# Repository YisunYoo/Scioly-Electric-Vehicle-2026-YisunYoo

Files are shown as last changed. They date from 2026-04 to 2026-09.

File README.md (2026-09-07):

https://github.com/user-attachments/assets/1983c1e8-5cba-4048-b536-1d948fe2c736

# Scioly-Electric-Vehicle-2026
Full documentation for vehicle built for Science Olympiad division C Electric Vehicle event 
#
Built by Yisun "Ben" Yoo , Savannah Country Day School class of 2027
#
**#1 EV in 2026 Georgia state Science Olympiad competition**

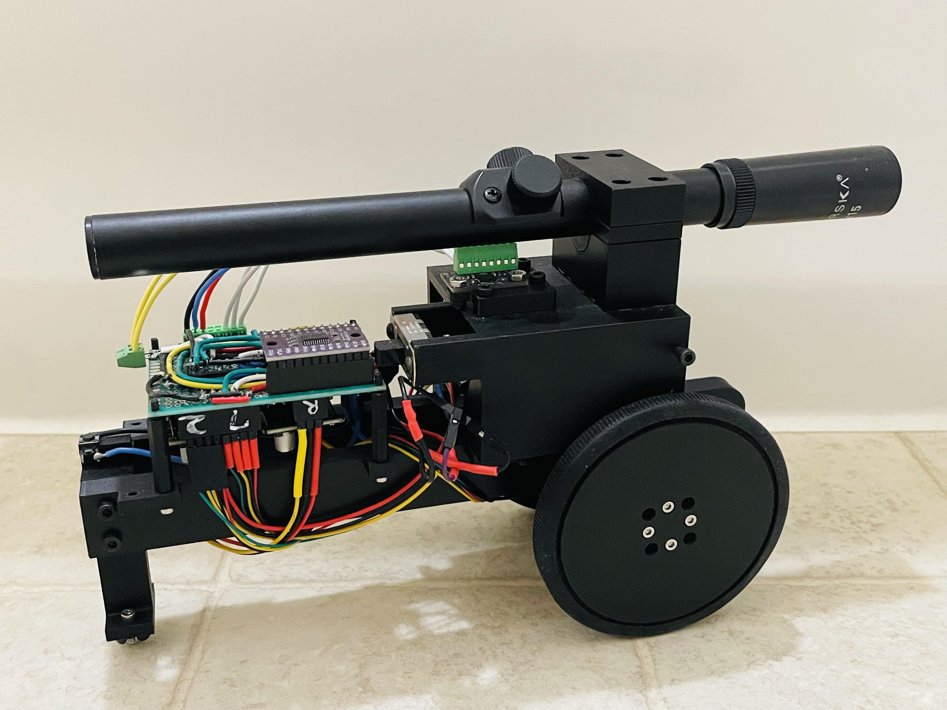
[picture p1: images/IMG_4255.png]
image failed


## Overview
Brief description of your vehicle's purpose and performance goals.

## Features
- Microcontroller: Arduino Nano ESP32
- IMU: BNO_08X
- Batteries: 8 AA 1.2v NiMH rechargeble
- Motor: 4015 gimbal BLDC motor (~400rpm max with 8 1.2vAA batteries)
- Encoder: AS5600 (0.087deg accuracy)

## Vehicle accuracy:
-   +- 1.5cm
-   +- 0.5s
-   gate width minimum: 13cm

## Quick Start
1. Install Arduino IDE
2. Install ESP32 board package
3. Upload `firmware/vehicle-controller.ino`

## Documentation
- [Circuit Design](circuit/diagrams/main-circuit.md)
- [Bill of Materials](docs/BOM.md)
- [3D Models](3d-models/)

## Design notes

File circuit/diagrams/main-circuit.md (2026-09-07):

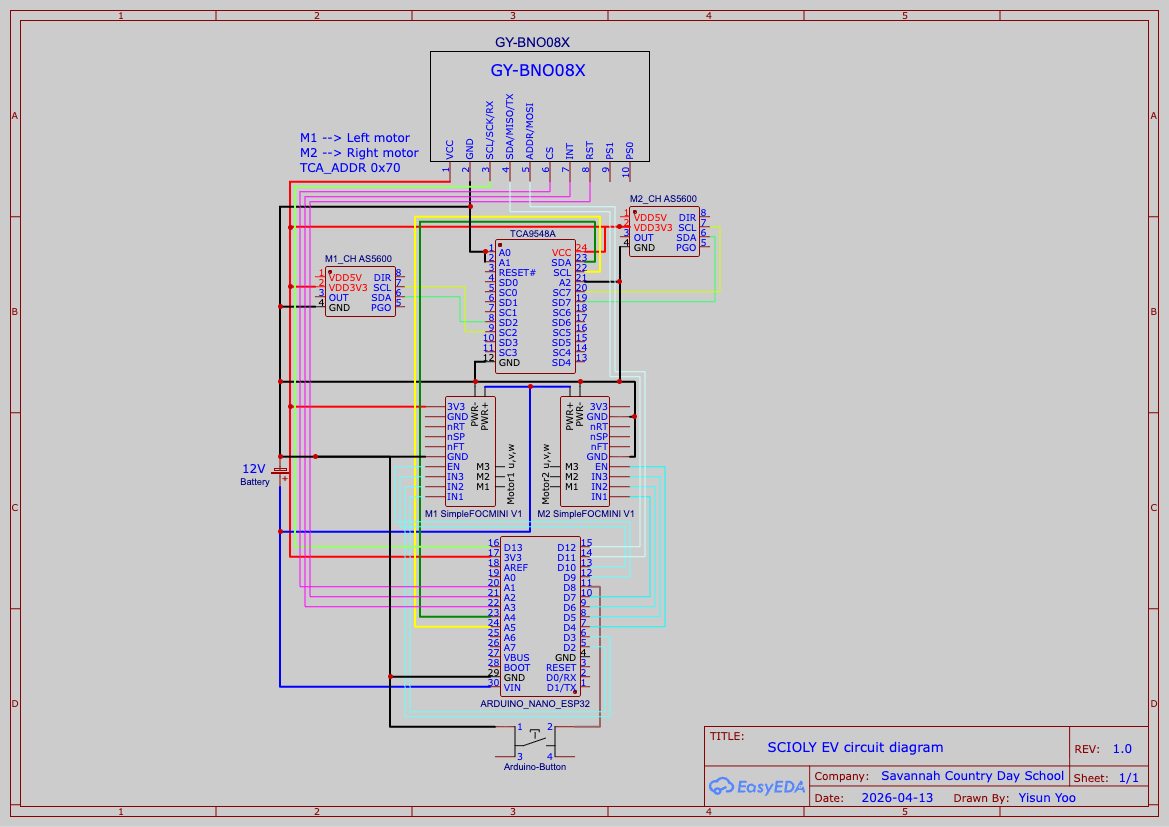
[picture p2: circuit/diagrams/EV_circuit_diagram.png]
image failed


# Circuit Specification

* PROJECT: SCIOLY EV Circuit Diagram
* DOCUMENTATION: Main Circuit Netlist and Pin Specifications
* REVISION: 1.0
* DATE: 2026-04-13
* COMPANY/TEAM: Savannah Country Day School
* DRAWN BY: Yisun Yoo
* CREATED BY: Yisun Yoo
* SOFTWARE: EasyEDA

# 1. SYSTEM SPECIFICATIONS & HARDWARE NOTES

* Microcontroller: Arduino Nano ESP32
* Power Source: 12V Battery (powers the Arduino VIN and motor drivers)
* Motor Driver Configuration: 
  - M1 = Left Motor Driver (SimpleFOCMini V1)
  - M2 = Right Motor Driver (SimpleFOCMini V1)
* I2C Multiplexer: TCA9548A (Address: 0x70)
  - All address pins (A0, A1, A2) are tied to GND.
* Motor: 4015 gimbal motor

# 2. POWER DISTRIBUTION & BUS RAILS

* 12V Main Rail:
  - Battery (+) ---> Arduino Nano ESP32 (Pin 30: VIN)
  - Battery (+) ---> M1 SimpleFOCMini V1 (PWR+)
  - Battery (+) ---> M2 SimpleFOCMini V1 (PWR+)

* 5V Logic Rail (VBUS):
  - Arduino Nano ESP32 (Pin 28: VBUS) ---> TCA9548A (Pin 24: VCC)
  - Arduino Nano ESP32 (Pin 28: VBUS) ---> M1_CH AS5600 Encoder (Pin 1: VDD5V)
  - Arduino Nano ESP32 (Pin 28: VBUS) ---> M2_CH AS5600 Encoder (Pin 1: VDD5V)

* 3.3V Logic Rail:
  - Arduino Nano ESP32 (Pin 17: 3V3) ---> GY-BNO08X IMU (Pin 1: VCC)
  - Arduino Nano ESP32 (Pin 17: 3V3) ---> M1 SimpleFOCMini V1 (3V3)
  - Arduino Nano ESP32 (Pin 17: 3V3) ---> M2 SimpleFOCMini V1 (3V3)

* Common Ground (GND):
  - Linked across Battery (-),
  - Arduino Nano ESP32 (Pin 29: GND),
  - TCA9548A (Pin 12: GND),
  - TCA9548A (Pins 1, 2, 3: A0/A1/A2),
  - GY-BNO08X (Pin 2: GND),
  - M1_CH AS5600 (Pin 5: GND),
  - M2_CH AS5600 (Pin 5: GND),
  - M1 SimpleFOCMini (GND),
  - M2 SimpleFOCMini (GND),
  - Arduino-Button (Pin 4).

# 3. PIN CONNECTIONS BY COMPONENT

[A] ARDUINO NANO ESP32
-------------------------------------------------------------------
* Pin 1  (D1/TX)   ---> TCA9548A (Pin 22: SCL)
* Pin 2  (D0/RX)   ---> TCA9548A (Pin 23: SDA)
* Pin 5  (D2)      ---> Arduino-Button (Pin 3)
* Pin 6  (D3)      ---> Tied to BOTH M1 (nRT) and M2 (nRT)
* Pin 7  (D4)      ---> M2 SimpleFOCMini V1 (nSP)
* Pin 8  (D5)      ---> M2 SimpleFOCMini V1 (nFT)
* Pin 9  (D6)      ---> M2 SimpleFOCMini V1 (EN)
* Pin 10 (D7)      ---> M2 SimpleFOCMini V1 (M3)
* Pin 11 (D8)      ---> M2 SimpleFOCMini V1 (M2)
* Pin 12 (D9)      ---> M2 SimpleFOCMini V1 (M1)
* Pin 13 (D10)     ---> M2 SimpleFOCMini V1 (IN3)
* Pin 14 (D11)     ---> M2 SimpleFOCMini V1 (IN2)
* Pin 15 (D12)     ---> M2 SimpleFOCMini V1 (IN1)
* Pin 16 (D13)     ---> M1 SimpleFOCMini V1 (IN1)
* Pin 17 (3V3)     ---> 3.3V Power Rail
* Pin 19 (A0)      ---> M1 SimpleFOCMini V1 (IN2)
* Pin 20 (A1)      ---> M1 SimpleFOCMini V1 (IN3)
* Pin 21 (A2)      ---> M1 SimpleFOCMini V1 (M1)
* Pin 22 (A3)      ---> M1 SimpleFOCMini V1 (M2)
* Pin 23 (A4)      ---> M1 SimpleFOCMini V1 (M3)
* Pin 24 (A5)      ---> M1 SimpleFOCMini V1 (EN)
* Pin 25 (A6)      ---> M1 SimpleFOCMini V1 (nFT)
* Pin 26 (A7)      ---> M1 SimpleFOCMini V1 (nSP)
* Pin 28 (VBUS)    ---> 5V Power Rail
* Pin 29 (GND)     ---> Common Ground Rail
* Pin 30 (VIN)     ---> 12V Battery (+)

[B] TCA9548A I2C MULTIPLEXER (Addr: 0x70)
-------------------------------------------------------------------
* Pin 1  (A0)      ---> GND
* Pin 2  (A1)      ---> GND
* Pin 3  (A2)      ---> GND
* Pin 5  (SD0)     ---> GY-BNO08X IMU (Pin 4: SDA/MISO/TX)
* Pin 6  (SC0)     ---> GY-BNO08X IMU (Pin 3: SCL/SCK/RX)
* Pin 7  (SD1)     ---> M1_CH AS5600 Left Encoder (Pin 4: SDA)
* Pin 8  (SC1)     ---> M1_CH AS5600 Left Encoder (Pin 3: SCL)
* Pin 9  (SD2)     ---> M2_CH AS5600 Right Encoder (Pin 4: SDA)
* Pin 10 (SC2)     ---> M2_CH AS5600 Right Encoder (Pin 3: SCL)
* Pin 12 (GND)     ---> GND
* Pin 22 (SCL)     ---> Arduino Nano ESP32 (Pin 1: D1/TX)
* Pin 23 (SDA)     ---> Arduino Nano ESP32 (Pin 2: D0/RX)
* Pin 24 (VCC)     ---> 5V Rail (VBUS)

[C] GY-BNO08X IMU SENSOR (Channel 0)
-------------------------------------------------------------------
* Pin 1 (VCC)        ---> 3.3V Rail
* Pin 2 (GND)        ---> GND
* Pin 3 (SCL/SCK/RX) ---> TCA9548A (Pin 6: SC0)
* Pin 4 (SDA/MISO/TX)---> TCA9548A (Pin 5: SD0)
* **Pins 5-10 (ADDR, CS, INT, RST, PS1, PS0) are UNCONNECTED.**

[D] M1_CH AS5600 ENCODER - LEFT MOTOR (Channel 1)
-------------------------------------------------------------------
* Pin 1 (VDD5V)  ---> 5V Rail (VBUS)
* Pin 3 (SCL)    ---> TCA9548A (Pin 8: SC1)
* Pin 4 (SDA)    ---> TCA9548A (Pin 7: SD1)
* Pin 5 (GND)    ---> GND
* **Pins 2 (VDD3V3), 6 (PGO), 7 (DIR) are UNCONNECTED.**

[E] M2_CH AS5600 ENCODER - RIGHT MOTOR (Channel 2)
-------------------------------------------------------------------
* Pin 1 (VDD5V)  ---> 5V Rail (VBUS)
* Pin 3 (SCL)    ---> TCA9548A (Pin 10: SC2)
* Pin 4 (SDA)    ---> TCA9548A (Pin 9: SD2)
* Pin 5 (GND)    ---> GND
* **Pins 2 (VDD3V3), 6 (PGO), 7 (DIR) are UNCONNECTED.**

[F] M1 SIMPLEFOCMINI V1 - LEFT MOTOR DRIVER
-------------------------------------------------------------------
* PWR+          ---> 12V Battery (+)
* PWR- / GND    ---> GND
* 3V3           ---> 3.3V Rail
* nRT           ---> Arduino Nano ESP32 (Pin 6: D3)
* nSP           ---> Arduino Nano ESP32 (Pin 26: A7)
* nFT           ---> Arduino Nano ESP32 (Pin 25: A6)
* EN            ---> Arduino Nano ESP32 (Pin 24: A5)
* M3            ---> Arduino Nano ESP32 (Pin 23: A4)
* M2            ---> Arduino Nano ESP32 (Pin 22: A3)
* M1            ---> Arduino Nano ESP32 (Pin 21: A2)
* IN3           ---> Arduino Nano ESP32 (Pin 20: A1)
* IN2           ---> Arduino Nano ESP32 (Pin 19: A0)
* IN1           ---> Arduino Nano ESP32 (Pin 16: D13)
* Motor1 u,v,w  ---> 3-Phase outputs to Left Motor

[G] M2 SIMPLEFOCMINI V1 - RIGHT MOTOR DRIVER
-------------------------------------------------------------------
* PWR+          ---> 12V Battery (+)
* PWR- / GND    ---> GND
* 3V3           ---> 3.3V Rail
* nRT           ---> Arduino Nano ESP32 (Pin 6: D3)
* nSP           ---> Arduino Nano ESP32 (Pin 7: D4)
* nFT           ---> Arduino Nano ESP32 (Pin 8: D5)
* EN            ---> Arduino Nano ESP32 (Pin 9: D6)
* M3            ---> Arduino Nano ESP32 (Pin 10: D7)
* M2            ---> Arduino Nano ESP32 (Pin 11: D8)
* M1            ---> Arduino Nano ESP32 (Pin 12: D9)
* IN3           ---> Arduino Nano ESP32 (Pin 13: D10)
* IN2           ---> Arduino Nano ESP32 (Pin 14: D11)
* IN1           ---> Arduino Nano ESP32 (Pin 15: D12)
* Motor2 u,v,w  ---> 3-Phase outputs to Right Motor

[H] ARDUINO-BUTTON (System Input)
-------------------------------------------------------------------
* Pin 3 ---> Arduino Nano ESP32 (Pin 5: D2)
* Pin 4 ---> GND

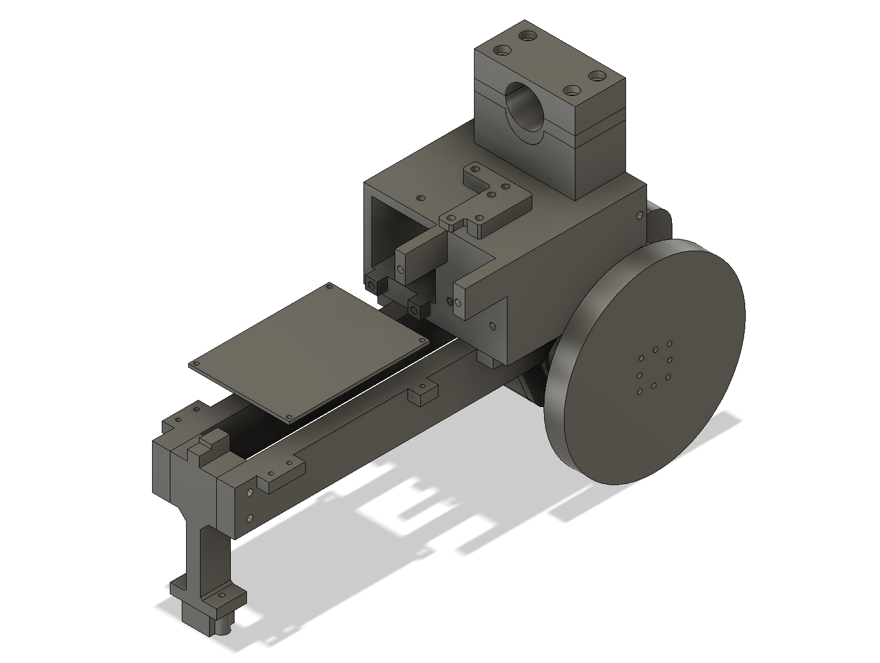
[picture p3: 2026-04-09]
images/3D model full view main.png

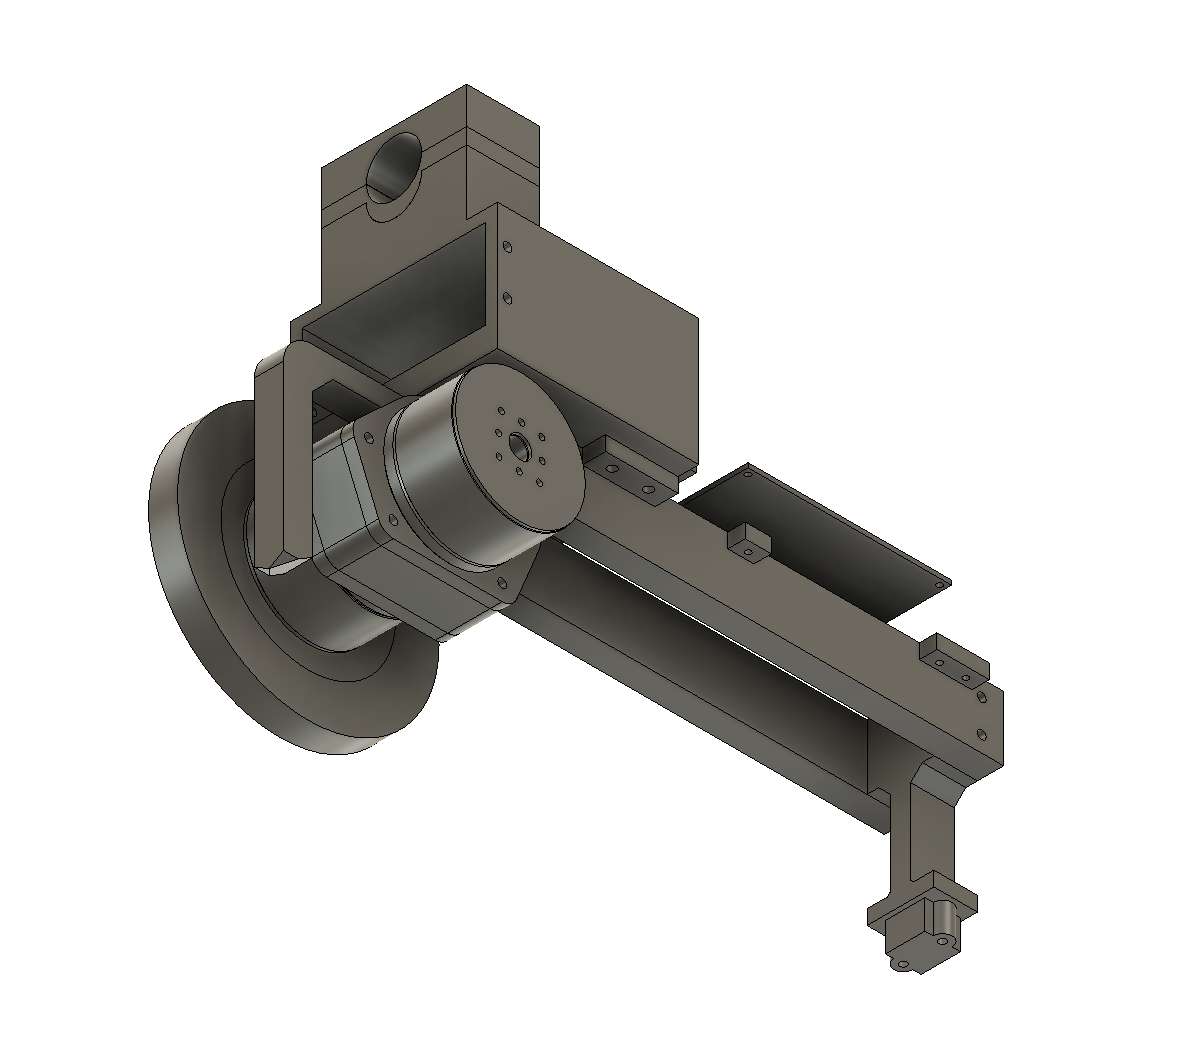
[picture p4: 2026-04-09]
images/3D model full view back.png

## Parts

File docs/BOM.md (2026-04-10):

## link to BOM

[link to BOM](https://docs.google.com/spreadsheets/d/1UVivWzAKgq3oz-N-Q3s3JLDuceGFrLYAt_yYQ4SD5Zs/edit?usp=sharing)

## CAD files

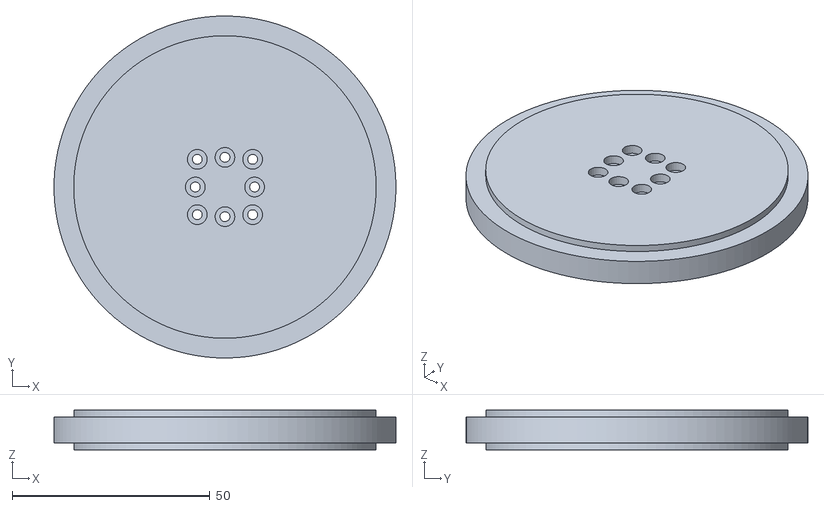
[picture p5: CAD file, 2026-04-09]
3d-models/wheel hub.stl
86.5 x 86.5 x 10.0

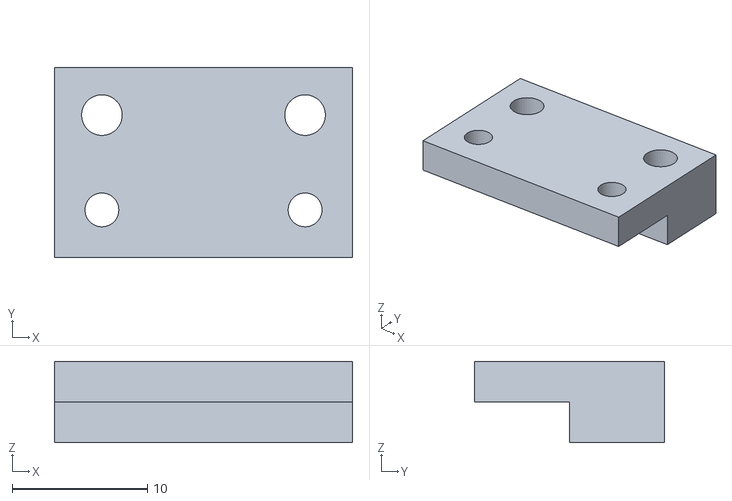
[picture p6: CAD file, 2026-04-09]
3d-models/IMU mount front.stl
22.0 x 14.0 x 6.00

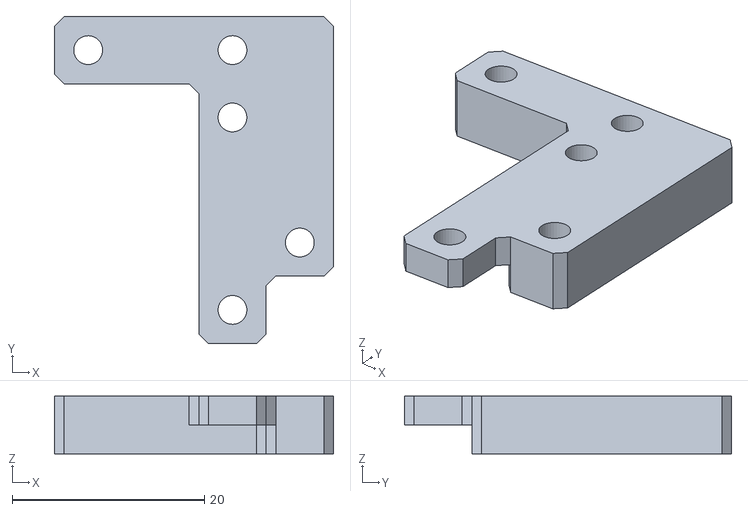
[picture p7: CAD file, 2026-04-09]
3d-models/IMU mount rear.stl
29.0 x 34.0 x 6.00

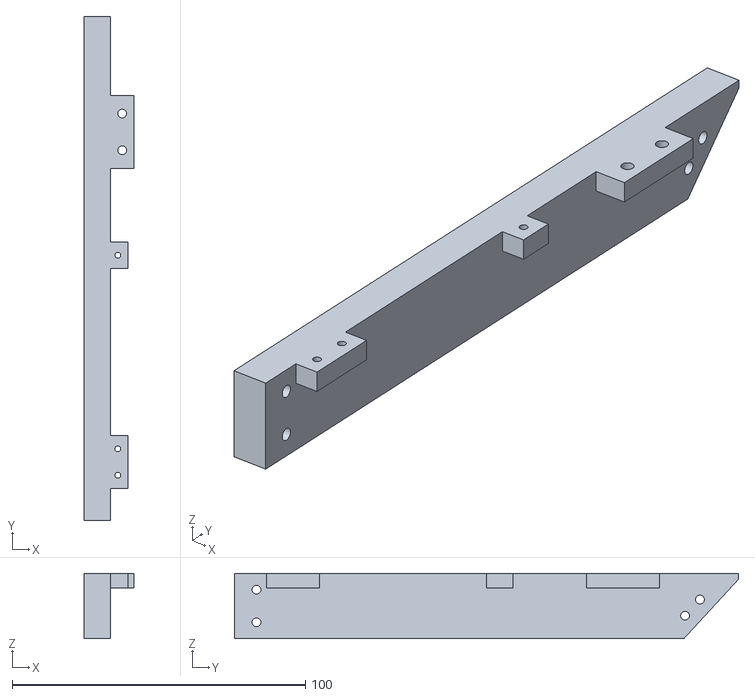
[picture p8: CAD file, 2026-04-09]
3d-models/right frame.stl
17.0 x 171.9 x 22.2

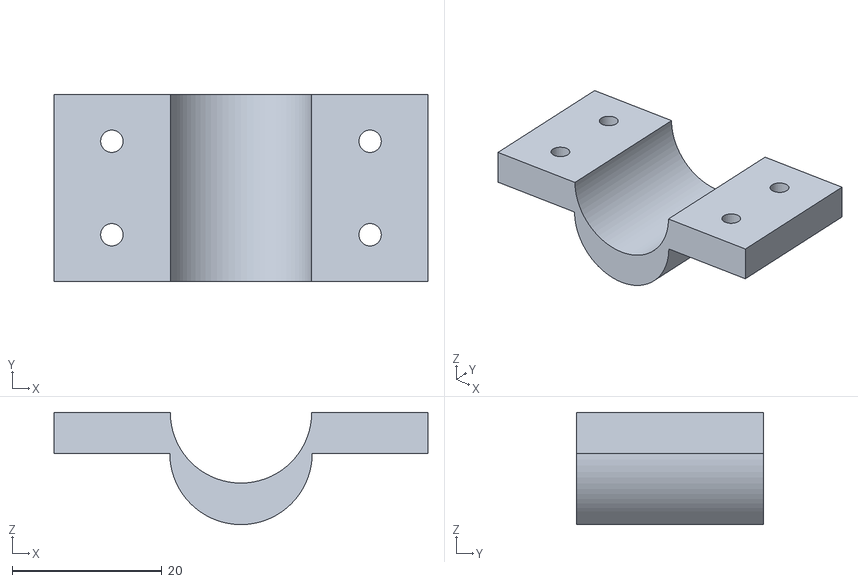
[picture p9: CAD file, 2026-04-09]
3d-models/heightadder.stl
50.0 x 25.0 x 15.0

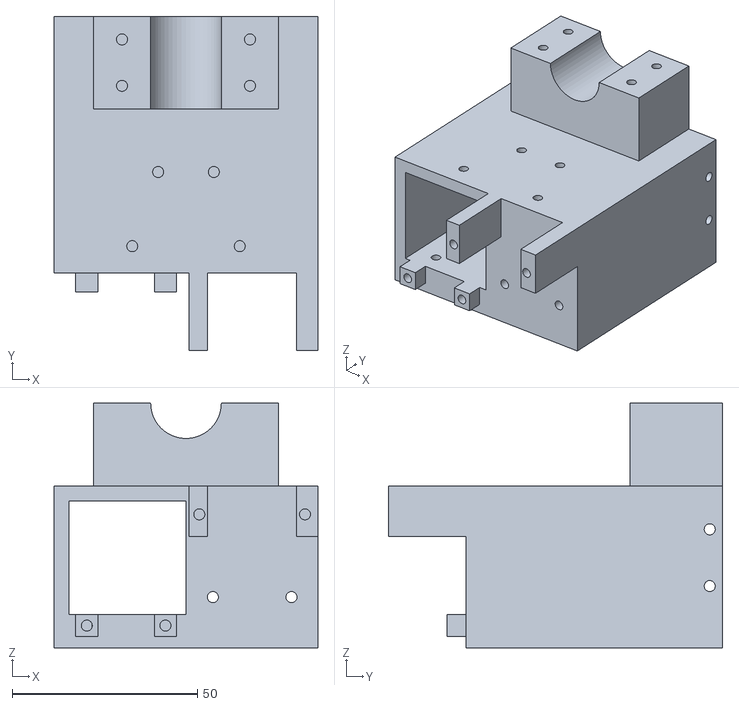
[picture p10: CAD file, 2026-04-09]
3d-models/battery holder.stl
71.2 x 90.2 x 66.0

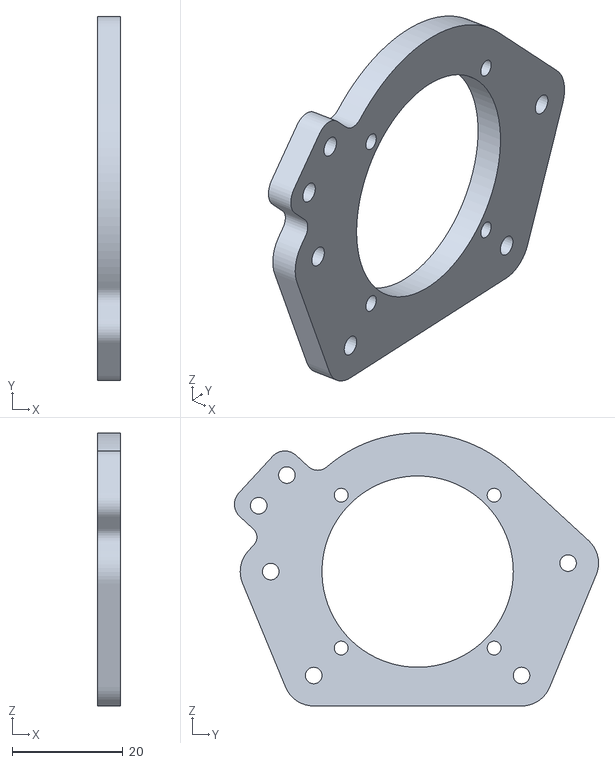
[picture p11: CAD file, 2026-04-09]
3d-models/Motor mount.stl
4.20 x 65.7 x 49.2

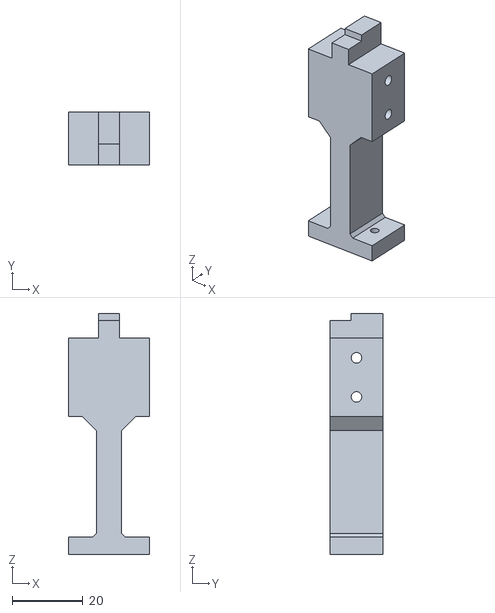
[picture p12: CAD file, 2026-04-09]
3d-models/rear stand.stl
23.0 x 15.0 x 68.3

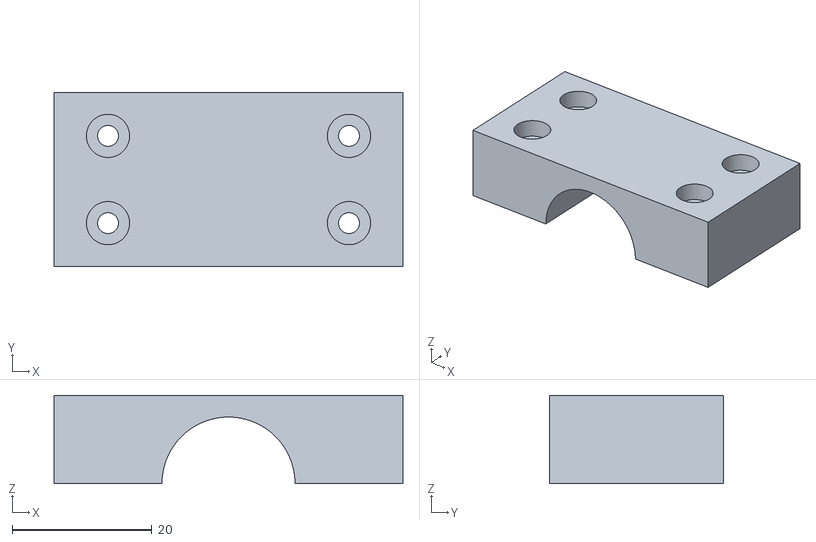
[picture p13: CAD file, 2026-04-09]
3d-models/scope top.stl
50.0 x 25.0 x 12.6

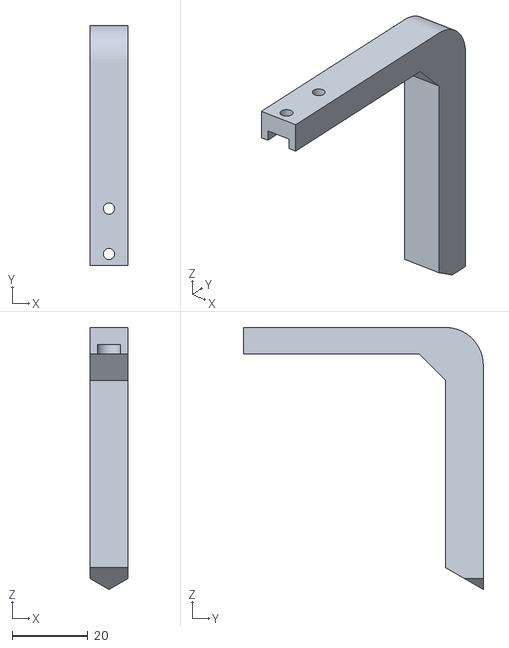
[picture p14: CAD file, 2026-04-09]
3d-models/MP.stl
10.0 x 63.4 x 69.3

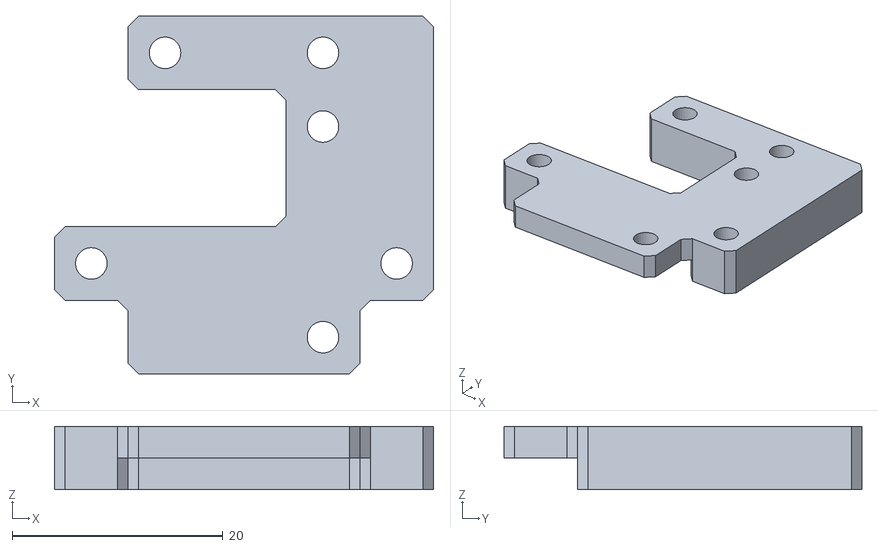
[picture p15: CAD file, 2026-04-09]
3d-models/IMU mount new.stl
36.0 x 34.0 x 6.00

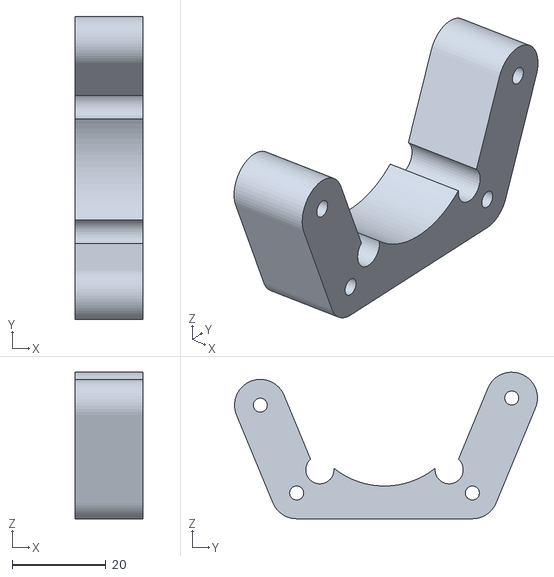
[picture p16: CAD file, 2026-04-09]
3d-models/spacer.stl
14.6 x 64.6 x 31.3

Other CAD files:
3d-models/left frame.stl

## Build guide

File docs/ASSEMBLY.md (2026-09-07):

Screenshot 2026-09-07 at 2 42 48 PM
Screenshot 2026-09-07 at 2 43 19 PM

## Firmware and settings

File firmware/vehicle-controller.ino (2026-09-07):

//by Yisun Yoo
//This is the final version. DO NOT CHANGE EXCEPT parameters of RUNSTART inside loop()

/*
  this code uses modified PID and odometry to move the differential drive robot with two motors from one point to another point as precise as possible, with a gate to pass through.
  the given sensors are
  1. two AS5600 encoder
  - Operating Voltage: 3.3V
  - Resolution: 12-bit
  - Accuracy: 0.087°
  - Output Method: I2C
  - Interface: GH1.25-4Pin

  2.BNO 055  absolute orientation sensor also with I2C

  The vehicle has wheel radius of 3.0cm, wheel diameter of 9.0cm (with wheel base of 8.1cm)
  The motor is 4015 gimbal motor 
  - wire to wire resistance of 4.8 ohms
  - rated voltage up to 24v and current max up to 4A
  - 11 pole pairs 

  The vehicle runs on eight AA batteries, with 1.2v rated voltage (rechargeble NiMH aa 2800mah)
  the voltage output when fully charged was meausred around 10V (+- 0.5V)
  The code should assume the batteries are always fully charged

  The vehicle has a reference point called measuring point(MP) 
  MP of the vehicle is placed 5cm in front of the vehicle midpoint of the axle connecting the two driving wheels.
  MP is the point that is measured from the target. (goal: MP = target)

  center line is the line connecting the starting point and the end point

  task: 
  1. the vehicle MP is placed on top of the starting point, and the vehicle is set to face the target point
  2. once the button is pressed, the vehicle should start to run
  3. the vehicle should pass though the gate
  4. the gate is placed to the left of the center line, and is placed on the midway between starting point and endpoint
  5. the outer side of the gate is fixed 100cm away from the center line
  6. the distance between the outer side and the inner side of the gate is chosen by us, and should be one of the inpput variable (gate distance < 100cm , the code should aim for going though middle of the gates)
  7. the vehicle should arrive at target point, which is defined by the distance, and target distance is another input variable. the possible distance vary from 700cm to 1000cm
  8. lastly, the vehicle should arrive at the target point at exact time set, which is the last input variable. the possible target time vary from 10 seconds to 20 seconds.
  9. the score is calculated as 100 + Distance Score + Time Score + Bonuses + Run Penalties
    c. Distance Score = 2.0 pt/cm x Vehicle Distance.
    d. Time Score = Absolute value of (Target Time - Run Time)
    e. Can Bonus = -0.5 x (110 - Inside Can Distance)
  10. the less score is better.

  plan:
  1. the vehicle will take three actions: moveStrait(from (y1 to y2 or x1 to x2))); turn(ang) degrees; and final precision movement for vehicle MP to precisely placed on target
*/

#include <Wire.h>
#include <SimpleFOC.h>
#include <AS5600.h>
#include "SparkFun_BNO08x_Arduino_Library.h"

AS5600 as5600;
BNO08x myIMU;

// ---- Motor pins ----
#define M1_U D2
#define M1_V D3
#define M1_W D10
#define M1_EN D9

#define M2_U D7
#define M2_V D6
#define M2_W D5
#define M2_EN D4

// ---- Encoder channels ----
#define M1_CH 2
#define M2_CH 7

// ---- Button ----
#define Button D8
const unsigned long debounce_ms = 50;
bool last_button = HIGH;
unsigned long last_change = 0;

// ---- IMU ----
#define BNO08X_CS A1
#define BNO08X_INT A3
#define BNO08X_RST A2
#define BNO08X_REPORT_INTERVAL_MS 25

struct EulerAngles {
  float yawDeg;
};

// ---- TCA9548A ----
#define TCA_ADDR 0x70
static void tcaSelect(uint8_t channel) {
  Wire.beginTransmission(TCA_ADDR);
  Wire.write(1 << channel);
  Wire.endTransmission();
}

bool readMuxedAS5600(uint8_t channel, uint16_t &raw, float &angleDeg, const char *label) {
  tcaSelect(channel);
  raw = as5600.rawAngle();
  const int err = as5600.lastError();
  if (err != AS5600_OK) {
    Serial.print("AS5600 read failed on ");
    Serial.print(label);
    Serial.print(" channel ");
    Serial.print(channel);
    Serial.print(" error ");
    Serial.println(err);
    return false;
  }

  angleDeg = raw * (360.0f / 4096.0f);
  return true;
}

float imuRawYawDeg = 0.0f;
float imuYawOffsetDeg = 0.0f;
bool imuHasOrientation = false;
bool imuReportsEnabled = false;
bool imuDebugPrinted = false;

// ---- Forward direction signs (adjust if needed) ----
const float M1_DIR = -1.0f;   // forward is + for motor1
const float M2_DIR = 1.0f;    // forward is + for motor2

MagneticSensorI2C sensor1 = MagneticSensorI2C(AS5600_I2C);
MagneticSensorI2C sensor2 = MagneticSensorI2C(AS5600_I2C);
BLDCMotor motor1 = BLDCMotor(11);
BLDCMotor motor2 = BLDCMotor(11);
BLDCDriver3PWM driver1 = BLDCDriver3PWM(M1_U, M1_V, M1_W, M1_EN);
BLDCDriver3PWM driver2 = BLDCDriver3PWM(M2_U, M2_V, M2_W, M2_EN);


// ========================== TUNE ================================= //
const float WHEEL_DIAMETER = 9.0f;
const float WHEEL_RADIUS = WHEEL_DIAMETER / 2.0f;
const float WHEEL_BASE = 8.5f;
const float MIN_VOLTAGE = 0.8f; //min voltage vehicle moves stably
const float max_voltage = 12.0f;

// ---- values ----
float M1_zero_pos = 0.0f;  //deg
float M2_zero_pos = 0.0f;  //deg
float M1_pos = 0.0f;       //rad
float M2_pos = 0.0f;       //rad
float x_pos = 0.0f;        //cm
float y_pos = 0.0f;        //cm
float yaw = 0.0f;          //deg
float startTime = 0.0f; //s
float runTime = 0.0f; //s

// ---- odometry ----
float M1_prev = 0.0f;      //rad
float M2_prev = 0.0f;      //rad
float yaw_prev = 0.0f;     //deg
float deg_prev = PI/2.0f;

uint16_t raw1 = 0, raw2 = 0;
float angle1 = 0, angle1_prev = 0, cumulative_angle1 = 0;
float angle2 = 0, angle2_prev = 0, cumulative_angle2 = 0;

// --- move equal ---
float M1_pos_ref = 0.0f;
float M2_pos_ref = 0.0f;

static inline float wrapPi(float a) {
  while (a > PI) a -= 2.0f * PI;
  while (a < -PI) a += 2.0f * PI;
  return a;
}

// ================================================ IMU FUNCTIONS ================================================

float clampUnit(float value) {
  if (value > 1.0f) {
    return 1.0f;
  }
  if (value < -1.0f) {
    return -1.0f;
  }
  return value;
}

float wrap180(float deg) {
  while (deg > 180.0f) {
    deg -= 360.0f;
  }
  while (deg < -180.0f) {
    deg += 360.0f;
  }
  return deg;
}

EulerAngles quaternionToEuler(float real, float i, float j, float k) {
  EulerAngles angles;
  const float sinyCosp = 2.0f * (real * k + i * j);
  const float cosyCosp = 1.0f - 2.0f * (j * j + k * k);
  angles.yawDeg = atan2f(sinyCosp, cosyCosp) * RAD_TO_DEG;

  return angles;
}

bool setIMUReports() {
  Serial.println("Setting desired reports");
  if (myIMU.enableGameRotationVector(BNO08X_REPORT_INTERVAL_MS) == true) {
    Serial.println(F("Rotation vector enabled"));
    Serial.println(F("Output in form i, j, k, real, accuracy"));
    imuReportsEnabled = true;
    imuDebugPrinted = false;
    delay(100);
    return true;
  }

  Serial.println("Could not enable rotation vector");
  imuReportsEnabled = false;
  delay(100);
  return false;
}

void zeroYaw() {
  if (!imuHasOrientation) {
    return;
  }

  imuYawOffsetDeg = imuRawYawDeg;
  yaw = 0.0f;
}

bool beginIMU() {
  Serial.println();
  Serial.println("BNO08x Read Example");

  const bool started = myIMU.beginSPI(BNO08X_CS, BNO08X_INT, BNO08X_RST);

  Serial.print("myIMU.begin: ");
  Serial.println(started ? "OK" : "FAIL");
  if (!started) return false;

  Serial.println("BNO08x found!");
  setIMUReports();

  const unsigned long retry_start_ms = millis();
  unsigned long last_retry_ms = retry_start_ms;
  while (!imuReportsEnabled && (millis() - retry_start_ms) < 1500) {
    if (myIMU.wasReset()) {
      Serial.print("sensor was reset ");
      setIMUReports();
    } else if ((millis() - last_retry_ms) >= 150) {
      last_retry_ms = millis();
      setIMUReports();
    }
    delay(10);
    Serial.println("?");
  }

  if (!imuReportsEnabled) return false;

  Serial.println("Reading events");
  delay(100);

  yaw = 0.0f;
  imuRawYawDeg = 0.0f;
  imuYawOffsetDeg = 0.0f;
  imuHasOrientation = false;

  Serial.println("beginIMU: done");
  return true;
}

float getYawDeg() {
  return yaw;
}
bool updateIMU_latest() {
  if (myIMU.wasReset()) {
    Serial.print("sensor was reset ");
    if (!setIMUReports()) return false;
  }

  if (!imuReportsEnabled) {
    if (!setIMUReports()) {
      return false;
    }
  }

  // Match the vendor examples: only poll once when INT says data is ready.
  // Repeatedly calling getSensorEvent() until false can force a 500ms timeout
  // inside the library and trigger an IMU reset when no fresh packet is queued.
  if (digitalRead(BNO08X_INT) != LOW) {
    return false;
  }

  if (!myIMU.getSensorEvent()) {
    return false;
  }

  if (myIMU.getSensorEventID() != SENSOR_REPORTID_GAME_ROTATION_VECTOR) {
    return false;
  }

  const float qi = myIMU.getGameQuatI();
  const float qj = myIMU.getGameQuatJ();
  const float qk = myIMU.getGameQuatK();
  const float qr = myIMU.getGameQuatReal();
  const EulerAngles a = quaternionToEuler(qr, qi, qj, qk);

  imuRawYawDeg = a.yawDeg;
  if (!imuHasOrientation) { imuHasOrientation = true; zeroYaw(); }

  yaw = wrap180(imuYawOffsetDeg - imuRawYawDeg); // update global yaw

  const bool got = true;
  if (got && !imuDebugPrinted) {
    //Serial.println("IMU stream active");
    imuDebugPrinted = true;
  }
  return got;
}

// ================================================ IMU FUNCTIONS END ================================================

void setupMotor(BLDCMotor &motor, BLDCDriver3PWM &driver, MagneticSensorI2C &sensor, uint8_t ch) {
  //encoder
  tcaSelect(ch);
  sensor.init(&Wire);
  motor.linkSensor(&sensor);
  sensor.min_elapsed_time = 0.001;

  //driver
  driver.voltage_power_supply = 10.6f;
  driver.voltage_limit = 10.0f;
  driver.pwm_frequency = 25000;
  driver.init();
  motor.linkDriver(&driver);
  float max_velocity = 30.0;                       // rad/s
  float motor_frequency_hz = max_velocity / (2 * PI); // ~16 Hz
  float filter_cutoff_hz = motor_frequency_hz * 5;    // ~80 Hz
  motor.LPF_velocity.Tf = 1.0 / (2.0 * PI * filter_cutoff_hz); 

  motor.controller = MotionControlType::velocity; //voltage
  motor.PID_velocity.P = 0.2;
  motor.PID_velocity.I = 20;

  motor.voltage_sensor_align = 3.0f;
  motor.sensor_direction = Direction::UNKNOWN;

  motor.init();
  motor.initFOC();
}

void resetValues() {
  // Encoder 1 snapshot (degrees)
  if (!readMuxedAS5600(M1_CH, raw1, angle1, "M1")) return;
  angle1_prev = angle1;
  cumulative_angle1 = angle1;
  M1_zero_pos = cumulative_angle1;   // NOTE: stored in degrees

  // Encoder 2 snapshot (degrees)
  if (!readMuxedAS5600(M2_CH, raw2, angle2, "M2")) return;
  angle2_prev = angle2;
  cumulative_angle2 = angle2;
  M2_zero_pos = cumulative_angle2;   // NOTE: stored in degrees

  zeroYaw();

  // Reset odometry state
  x_pos = 0.0f;
  y_pos = 0.0f;

  M1_pos = 0.0f;
  M2_pos = 0.0f;
  M1_prev = 0.0f;
  M2_prev = 0.0f;

  // Heading convention:
  // radians: PI/2 = North (+Y)
  // degrees: 0 = North
  deg_prev = PI * 0.5f;
  yaw = 0.0f;
  yaw_prev = 0.0f;

  M1_pos_ref = 0.0f;
  M2_pos_ref = 0.0f;

  startTime = millis() / 1000.0f;
}

void updateOdometry() {

  // ---- Encoder 1 (degrees -> cumulative degrees -> radians) ----
  if (!readMuxedAS5600(M1_CH, raw1, angle1, "M1")) return;

  float delta_angle1 = angle1 - angle1_prev;
  if (delta_angle1 < -180.0f) delta_angle1 += 360.0f;
  if (delta_angle1 >  180.0f) delta_angle1 -= 360.0f;

  cumulative_angle1 += delta_angle1;
  angle1_prev = angle1;

  // M1_zero_pos is in degrees
  M1_pos = (cumulative_angle1 - M1_zero_pos) * (PI / 180.0f) * M1_DIR; // radians


  // ---- Encoder 2 ----
  if (!readMuxedAS5600(M2_CH, raw2, angle2, "M2")) return;

  float delta_angle2 = angle2 - angle2_prev;
  if (delta_angle2 < -180.0f) delta_angle2 += 360.0f;
  if (delta_angle2 >  180.0f) delta_angle2 -= 360.0f;

  cumulative_angle2 += delta_angle2;
  angle2_prev = angle2;

  //yaw calculation
  updateIMU_latest();
  while (yaw < 0.0f) yaw += 360.0f;
  while (yaw >= 360.0f) yaw -= 360.0f;

  // M2_zero_pos is in degrees
  M2_pos = (cumulative_angle2 - M2_zero_pos) * (PI / 180.0f) * M2_DIR; // radians

  // ---- Differential drive odometry ----
  float D_l = radToCm(M1_pos - M1_prev);         // cm
  float D_r = radToCm(M2_pos - M2_prev);         // cm
  float D_avg = 0.5f * (D_l + D_r);              // cm
  float D_yaw_deg = yaw - yaw_prev;
  if (D_yaw_deg > 180.0f) D_yaw_deg -= 360.0f;
  if (D_yaw_deg < -180.0f) D_yaw_deg += 360.0f;
  float D_ang = -D_yaw_deg * PI / 180.0f;   // minus sign: yaw is CW+, math angle is CCW+


  float heading_mid = degToRad(yaw_prev) + 0.5f * D_ang;   // radians, PI/2 is North
  x_pos += D_avg * cosf(heading_mid);            // +X east
  y_pos += D_avg * sinf(heading_mid);            // +Y north

  deg_prev = wrapPi(deg_prev + D_ang);           // radians

  // Convert radians heading to compass-like yaw:
  // yaw = 0 at North, clockwise positive

  M1_prev = M1_pos;
  M2_prev = M2_pos;
  yaw_prev = yaw;
}

float radToCm(float rad){
  return (float) rad * WHEEL_RADIUS;
}
float degToRad(float deg){ //0 deg north to 0rad east (for BNO 055)
  float rad0 = (90-deg) * PI / 180.0f;
  rad0 = fmod(rad0, 2.0f * PI);
  if (rad0 < 0) {
    rad0 += 2.0f * PI;
  }
  return rad0;
}
float rpsToRads(float rps){ //rps to radians per seconds
  return (float) rps*2.0*PI;
}
float RadsTorps(float Rads){
  return (float) Rads/(2.0*PI);
}

void moveEqual(int dir , float base_voltage){ // dir = 1 --> forward. dir = -1 --> rotate
  motor1.controller = MotionControlType::torque; //setting voltage control mode 
  motor2.controller = MotionControlType::torque; //setting voltage control mode 
  motor1.enable();
  motor2.enable();

  float M1_ang_displacement = M1_pos - M1_pos_ref;
  float M2_ang_displacement = M2_pos - M2_pos_ref;

  if(dir == 1){
    motor1.move(M1_DIR * constrain(base_voltage + 5.0f * (M2_ang_displacement - M1_ang_displacement),-12,12)); //voltage
    motor2.move(M2_DIR * constrain(base_voltage + 5.0f * (M1_ang_displacement - M2_ang_displacement),-12,12)); //voltage
  }

  if(dir == -1){
    motor1.move(M1_DIR * constrain(base_voltage - 5.0f * (M2_ang_displacement + M1_ang_displacement),-12,12));
    motor2.move(M2_DIR * constrain(-1.0f * base_voltage - 5.0f * (M2_ang_displacement + M1_ang_displacement),-12,12));
  }

}
//move straight using horizontal difference in odometry
void moveStrait(float x1, float y1, float x2, float y2, float base_rps, bool accelramp, bool decelramp) {
  if (y2 < y1) return;
  if (x1 != x2) return; // vertical only

  motor1.controller = MotionControlType::velocity; 
  motor2.controller = MotionControlType::velocity; 

  motor1.enable();
  motor2.enable();
  bool heading_solved = true;

  const float MAX_RPS = 5.0f;
  base_rps = constrain(base_rps, 0.0f, MAX_RPS);

  unsigned long lastUpdateTime = millis();
  unsigned long currentTime = millis();

  const double interval = 3; // ms
  unsigned long lastFOC_us = 0;
  const unsigned long foc_interval_us = 1000; // ~1kHz

  // Lateral/heading steering (rps domain)
  const float x_P = 0.05f;    // rps/cm
  const float x_I = 0.005f;    // rps/(cm*s)
  const float x_D = 0.01f;    // rps/(cm/s)
  const float yaw_P = 0.021f; // rps/deg
  const float horizontal_I_threshold = 4.0f; // cm

  // Base speed profile
  const float accel_P = 0.02f; // rps/cm^2
  const float decel_P = 0.2f; // rps/cm
  const float min_move_rps = 0.5f;

  // heading barrier by side of centerline
  const float YAW_LIM = 45.0f;   // deg
  const float YAW_LIM_CLOSE = 10.0f;
  const float YAW_LIM_CLOSE_SPECIAL_MULTIPLIER = 4.0f;
  const float excessive_yaw_P = 0.06f; //rps / deg
  const float X_EPS   = 4.0f;    // cm deadband around centerline

  float x_err_prev = 0.0f;
  float i_x_err = 0.0f;

  updateOdometry();
  float y_start = y_pos;

  const unsigned long start_ms = millis();
  const unsigned long timeout_ms = 30000; // safety

  while (fabs(y2 - y_pos) > 1.0f) {
    if (millis() - start_ms > timeout_ms) break;

    unsigned long now_us = micros();
    if ((unsigned long)(now_us - lastFOC_us) >= foc_interval_us) {
      lastFOC_us = now_us;
      tcaSelect(M1_CH); motor1.loopFOC();
      tcaSelect(M2_CH); motor2.loopFOC();
    }

    currentTime = millis();
    if (currentTime - lastUpdateTime >= interval) {
      updateOdometry();

      float yaw_signed = yaw;
      if (yaw_signed > 180.0f) yaw_signed -= 360.0f; // [-180,180]

      float x_err = x_pos - x2; // cm
      float y_err = y2 - y_pos; // cm

      float target_deg = 0.0f; // north
      float yaw_err = wrapPi(degToRad(target_deg) - degToRad(yaw)) * 180.0f / PI; // deg

      float dt = (float)(currentTime - lastUpdateTime) / 1000.0f;
      lastUpdateTime = currentTime;

      if (fabs(x_err) < horizontal_I_threshold) i_x_err += x_err * dt;
      else i_x_err = 0.0f;

      float d_x_err = (x_err - x_err_prev) / dt;
      x_err_prev = x_err;

      float steer_rps = x_P * x_err + x_D * d_x_err + x_I * i_x_err + yaw_P * yaw_err;

      float y_dist = y_pos - y_start;
      float accel_base = constrain(accel_P * ((y_dist + 1.0f) * (y_dist + 1.0f)), min_move_rps, base_rps);
      float decel_base = constrain(decel_P * y_err,  min_move_rps, base_rps);

      float base = base_rps;
      if (accel_P * y_dist < base && accelramp == true) base = accel_base;
      if (decel_P * y_err  < base && decelramp == true) base = decel_base;

      if (x_err > X_EPS && yaw_signed <= -YAW_LIM && steer_rps > 0.0f) {
        // right of line, already too left, and command still turns more left
        float excessive_yaw_err = yaw_signed - (-YAW_LIM);   // negative when too left
        steer_rps = excessive_yaw_P * excessive_yaw_err;     // drives back toward -YAW_LIM
      }

      if (x_err < -X_EPS && yaw_signed >= YAW_LIM && steer_rps < 0.0f) {
        // left of line, already too right, and command still turns more right
        float excessive_yaw_err = yaw_signed - (YAW_LIM);    // positive when too right
        steer_rps = excessive_yaw_P * excessive_yaw_err;     // drives back toward +YAW_LIM
      }

      // normal magnitude limit after directional barrier
      float steer_lim = min(1.2f, 0.3f * base);
      steer_rps = constrain(steer_rps, -steer_lim, steer_lim);

      if((fabs(x_err) < X_EPS && fabs(yaw_signed) > YAW_LIM_CLOSE) || (heading_solved == false)){ //close but too much right or left
        heading_solved = false;
        steer_rps = YAW_LIM_CLOSE_SPECIAL_MULTIPLIER * yaw_P * yaw_err; //too much heading error when close special feedback
        if (fabs(yaw_signed) < YAW_LIM_CLOSE) heading_solved = true;
      }
      float left_rps  = constrain(base - steer_rps, 0.0f, MAX_RPS);
      float right_rps = constrain(base + steer_rps, 0.0f, MAX_RPS);

      motor1.move(rpsToRads(left_rps)  * M1_DIR);
      motor2.move(rpsToRads(right_rps) * M2_DIR);
    }
  }

  motor1.move(0.0f);
  motor2.move(0.0f);
}

//turn to any angle (currently in voltage mode)
void moveTurn(float target_deg){

  motor1.controller = MotionControlType::torque; //setting voltage control mode 
  motor2.controller = MotionControlType::torque; //setting voltage control mode 
  motor1.enable();
  motor2.enable();
  unsigned long lastUpdateTime = 0;
  unsigned long currentTime = millis();

  const long interval = 5; //ms

  unsigned long lastFOC_us = 0;
  const unsigned long foc_interval_us = 1000; // ~1kHz

  const float Ang_P = 0.07f; // V/deg
  float Ang_I = 0.40f; //  V*s / deg
  const float Ang_D = 0.008f; // V / (deg/s) 0.006

  float deg_err_prev = 0.0f;
  float i_deg_err = 0.0f;
  float d_deg_err = 0.0f;
  float deg_err = 360.0f;

  float voltage_M1 = 0.0f;
  float voltage_M2 = 0.0f;

  M1_pos_ref = M1_pos;
  M2_pos_ref = M2_pos;

  lastUpdateTime = millis();
  lastFOC_us = micros();

  while(fabs(deg_err) > 0.2 || fabs(d_deg_err) > 1){
    unsigned long now_us = micros();
    if ((unsigned long)(now_us - lastFOC_us) >= foc_interval_us) {
      lastFOC_us = now_us;
      tcaSelect(M1_CH);
      motor1.loopFOC();
      tcaSelect(M2_CH);
      motor2.loopFOC();
      
    }
    currentTime = millis();
    if (currentTime - lastUpdateTime >= interval) {

      updateOdometry();

      deg_err = wrapPi(degToRad(target_deg) - degToRad(yaw)) * 180.0f / PI; //positive if vehicle heading right (deg)
      float dt = (float) (currentTime - lastUpdateTime)/1000.0f;
      if (fabs(deg_err) > 10) i_deg_err = 0.0f;
      if (fabs(deg_err) < 10) i_deg_err = (float) i_deg_err + (deg_err * dt);
      d_deg_err = (float) (deg_err - deg_err_prev) / dt;

      deg_err_prev = deg_err;

      float ang_cmd = constrain(Ang_P * deg_err + Ang_I * i_deg_err + Ang_D * d_deg_err,-1.2,1.2);
      moveEqual(-1 , -1.0f * ang_cmd);
      lastUpdateTime = currentTime;
    }
  }
}
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
void loop(){
  unsigned long now = millis();

  bool btn = digitalRead(Button);
  if (btn != last_button && (now - last_change) > debounce_ms) {
    last_change = now;
    if (btn == LOW) {
      RUNSTART(920, 15, 10, -1); // distance cm, can distance cm , time s, -1 if left 1 if right
    }
    last_button = btn;
  }

  updateOdometry();
  printTelemetry();
}

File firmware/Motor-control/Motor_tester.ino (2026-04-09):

#include <Wire.h>
#include <SimpleFOC.h>

// ---- Motor pins ----
#define M1_U 12
#define M1_V 11
#define M1_W 10
#define M1_EN 9

#define M2_U 7
#define M2_V 6
#define M2_W 5
#define M2_EN 4

// ---- Encoder channels ----
#define M1_CH 2
#define M2_CH 7

// ---- Button ----
#define Button 8
const unsigned long debounce_ms = 50;
bool last_button = HIGH;
unsigned long last_change = 0;
bool ONOFF = 0;

float M1_pos = 0.0f;       //rad
float M2_pos = 0.0f;       //rad

float M1_pos_prev = 0.0f;
float M2_pos_prev = 0.0f;

long vel_time = micros();
long vel_time_prev = micros();

float M1_vel = 0.0f; //rad / s
float M2_vel = 0.0f; //rad / s

float dt = 0.0f;

float M1_i_vel = 0.0f;
float M2_i_vel = 0.0f;

// ---- TCA9548A ----
#define TCA_ADDR 0x70
static void tcaSelect(uint8_t channel) {
  Wire.beginTransmission(TCA_ADDR);
  Wire.write(1 << channel);
  Wire.endTransmission();
}

// ---- Forward direction signs (adjust if needed) ----
const float M1_DIR = -1.0f;   // forward is + for motor1
const float M2_DIR = 1.0f;    // forward is + for motor2

MagneticSensorI2C sensor1 = MagneticSensorI2C(AS5600_I2C);
MagneticSensorI2C sensor2 = MagneticSensorI2C(AS5600_I2C);

BLDCMotor motor1 = BLDCMotor(11);
BLDCMotor motor2 = BLDCMotor(11);

BLDCDriver3PWM driver1 = BLDCDriver3PWM(M1_U, M1_V, M1_W, M1_EN);
BLDCDriver3PWM driver2 = BLDCDriver3PWM(M2_U, M2_V, M2_W, M2_EN);

void setupMotor(BLDCMotor &motor, BLDCDriver3PWM &driver, MagneticSensorI2C &sensor, uint8_t ch) {
  //encoder
  tcaSelect(ch);
  sensor.init(&Wire);
  motor.linkSensor(&sensor);

  //driver
  driver.voltage_power_supply = 12.0f;
  driver.voltage_limit = 12.0f;
  driver.pwm_frequency = 25000;
  driver.init();
  motor.linkDriver(&driver);

  motor.controller = MotionControlType::torque; //voltage

  motor.current_limit = 1.5;
  motor.voltage_limit = 12.0f;

  motor.voltage_sensor_align = 3.0f;
  motor.sensor_direction = Direction::UNKNOWN;

  motor.init();
  motor.initFOC();
}

void updateVelocity(){
  vel_time = micros();
  tcaSelect(M1_CH);
  motor1.loopFOC();
  M1_pos = (motor1.shaftAngle()) * M1_DIR; //rad (sign corrected)

  //motor 2 angle
  tcaSelect(M2_CH);
  motor2.loopFOC();
  M2_pos = (motor2.shaftAngle()) * M2_DIR; //rad (sign corrected)

  dt = (float) (vel_time - vel_time_prev) / 1000000.0f;

  M1_vel = ((float) (M1_pos - M1_pos_prev) / dt) / (2.0f*PI); //rps
  M2_vel = ((float) (M2_pos - M2_pos_prev) / dt) / (2.0f*PI); //rps

  vel_time_prev = vel_time;
  M1_pos_prev = M1_pos;
  M2_pos_prev = M2_pos;
}
void updateVelocityControl(float M1_targetVelocity , float M2_targetVelocity){ //rps
  const float velocity_P = 0.0f; //V / (rps)
  const float velocity_I = 5.0f; //V / R
  updateVelocity();
  float M1_vel_err = M1_targetVelocity - M1_vel;
  float M2_vel_err = M2_targetVelocity - M2_vel;

  M1_i_vel = M1_i_vel + M1_vel_err * dt;
  M2_i_vel = M2_i_vel + M2_vel_err * dt;

  float M1_vel_cmd = velocity_P * M1_vel_err + velocity_I * M1_i_vel;
  float M2_vel_cmd = velocity_P * M2_vel_err + velocity_I * M2_i_vel;

  motor1.move(constrain(M1_vel_cmd,-10,10) * M1_DIR);
  motor2.move(constrain(M2_vel_cmd,-10,10) * M2_DIR);
}

void setup() {
  // put your setup code here, to run once:
  Serial.begin(115200);

  Wire.begin(A4, A5);
  Wire.setClock(400000);

  pinMode(Button, INPUT_PULLUP);

  setupMotor(motor1, driver1, sensor1, M1_CH);
  setupMotor(motor2, driver2, sensor2, M2_CH);
}

unsigned long lastUpdateTime = 0;
unsigned long currentTime = millis();

const long interval = 1000; //ms

unsigned long lastFOC_us = 0;
const unsigned long foc_interval_us = 1000; // ~1kHz

void loop(){
  unsigned long now = millis();

  bool btn = digitalRead(Button);
  if (btn != last_button && (now - last_change) > debounce_ms) {
    last_change = now;
    if (btn == LOW) {
      (ONOFF == 0) ? ONOFF = 1 : ONOFF = 0;
    }
    last_button = btn;
  }
  unsigned long now_us = micros();
  if ((unsigned long)(now_us - lastFOC_us) >= foc_interval_us) {


    lastFOC_us = now_us;
    if (ONOFF == 1){
      motor1.enable();
      motor2.enable();
      updateVelocityControl(2 , 2);
    }else {
      motor1.disable();
      motor2.disable();;
    }
  }
  currentTime = millis();
  if (currentTime - lastUpdateTime >= interval) {
    Serial.print(M1_vel);
    Serial.print(" / ");
    Serial.println(M2_vel);
    lastUpdateTime = currentTime;
  }
}

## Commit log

2026-04-09 Update comments for I2C and SPI communication modes
    Added comments regarding I2C and SPI modes for clarity.
2026-04-09 Create main-circuit
2026-04-09 3D models stl
    [IMU mount front.stl, IMU mount new.stl, IMU mount rear.stl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]
2026-04-09 3dmodels added
    [IMU mount front.stl, IMU mount new.stl, IMU mount rear.stl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]
2026-04-10 Add link to BOM in documentation
2026-04-10 Add section header for PINS in CIRCUIT.md
2026-09-07 Document main circuit specifications and connections
    Added detailed specifications and pin connections for the main circuit diagram.
2026-09-07 Update wheel diameter from 6.0cm to 9.0cm
2026-09-07 Add image placeholder to main circuit diagram
2026-09-07 Fix image path in main circuit diagram
2026-09-07 Update main circuit documentation with specifications
    Added circuit specification details and updated formatting.
2026-09-07 Update headings in main-circuit.md to proper format
2026-09-07 Format pin connections for Arduino Nano ESP32
2026-09-07 Improve formatting and clarity of circuit connections
    Formatted the common ground and pin connections for better readability. Added emphasis on unconnected pins for clarity.
2026-09-07 Fix image paths in README.md
    Updated image paths in README for circuit diagram.
2026-09-07 Add additional image to main circuit diagram
2026-09-07 Update image path for EV circuit diagram
2026-09-07 Fix image path for circuit diagram
2026-09-07 Fix image path in main-circuit.md
2026-09-07 Refactor circuit documentation formatting
    Updated formatting for project specifications and section headers.
2026-09-07 Add images to ASSEMBLY.md documentation
2026-09-07 Update Circuit Design link in README
